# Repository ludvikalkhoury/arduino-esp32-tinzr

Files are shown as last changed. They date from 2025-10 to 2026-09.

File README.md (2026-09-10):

# TinZr ESP32-C3 Arduino Board Manager Package

This repository contains the **TinZr**, an ESP32-C3-based custom board definition for the Arduino IDE.  
It provides a clean, Boards-Manager-installable package so anyone can use your board with one simple URL.

## Publication
The manuscript describing this work is available at: https://www.sciencedirect.com/science/article/pii/S246806722600101X.
It is also included in this repository (`TinZr_Manuscript.pdf`). 

Additionally, all production materials, including printed circuit board (PCB) design files, 3D-printable enclosure models, and component lists, are available at: https://zenodo.org/records/21892119

If you use this work, please cite:
> **Alkhoury, L.**, Moore, T., Swissler, P., Hill, N. J., Shah, S. A., & Kam, M. (2026). TinZr: A compact wireless ESP32-C3 platform for multi-modal physiological sensor integration and data acquisition. HardwareX, e00833.

---
## Pinout
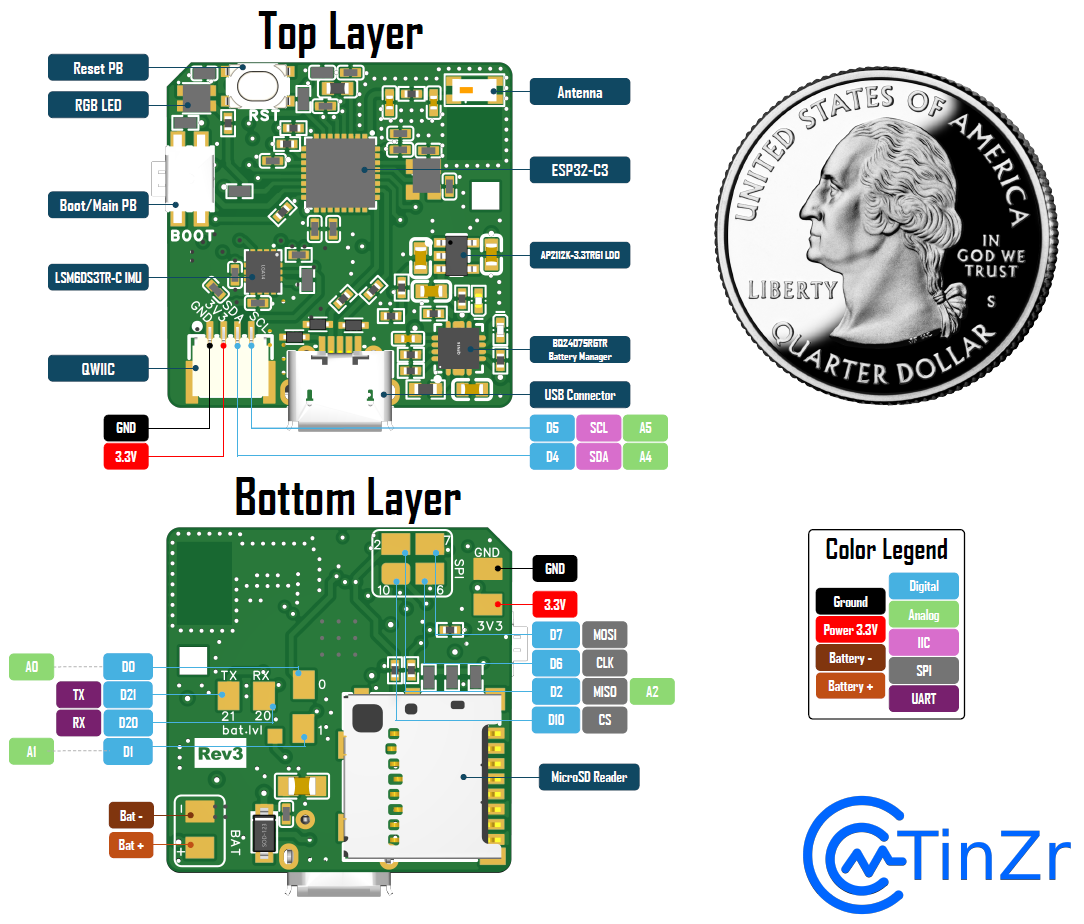
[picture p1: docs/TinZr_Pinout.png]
TinZr ESP32-C3 Pinout


## 🚀 Quick Install

### 1️⃣ Install Espressif ESP32
Open the Arduino IDE and go to:
- Go to **Tools → Board → Boards Manager**
- Find ``esp32 by Espressif Systems``
- Install *only* version `3.3.4`

**⚠️ IMPORTANT: This project is tested and supported exclusively with ESP32 core version `3.3.4`.**  
**Do NOT use any other version — builds may fail or behave incorrectly.**

### 2️⃣ Add the Boards Manager URL
Open the Arduino IDE and go to:

**File → Preferences → Additional Boards Manager URLs**, then paste:

```
https://ludvikalkhoury.github.io/TinZr/package_tinzr_index.json
```

Click **OK**.

### 3️⃣ Install the board package
In Arduino IDE:
- Go to **Tools → Board → Boards Manager**
- Search for **TinZr**
- Click **Install**

### 4️⃣ Select your board
Go to:

**Tools → Board → TinZr Boards → TinZr ESP32-C3 Rev5**

### 5️⃣ Install `TinZrConnect` as a Zipped Arduino Library
#### A) Create the ZIP (IMPORTANT: zip the *library folder*, not the whole TinZr repo)
- Navigate to the `libraries` directory. There you will find the `TinZrConnect` folder (the one that contains `library.properties`).
- Create a zipped version of the `TinZrConnect` folder, and name it `TinZrConnect.zip`.

#### B) Install the ZIP in Arduino IDE
1. In Arduino IDE, go to:
   - **Sketch → Include Library → Add .ZIP Library…**
2. Select `TinZrConnect.zip`
3. Wait for the confirmation message (bottom status bar).

#### C) Verify Installation
1. Go to:
   - **File → Examples**
2. Scroll to find:
   - **TinZrConnect**
3. Open an example sketch and compile.

If you see the examples and the sketch compiles, the library is installed correctly ✅

## 💡 Example Sketch (NeoPixel Test)

```cpp
#include <Arduino.h>
#include "TinZrCore.h" // this library declares TinZrCore TinZr
#include "TinZrLED.h"  // this library declares TinZrStatusLED TinZrLED

void setup() {
    TinZr.begin(25); //LED brightness is 25
}

void loop() {
    TinZrLED.setColor(255,0,0); delay(500);
    TinZrLED.setColor(0,255,0); delay(500);
    TinZrLED.setColor(0,0,255); delay(500);
}
```

#

Copyright © 2026 Ludvik Alkhoury

This software is licensed under the GNU General Public License v3.0.
Commercial licensing options are available upon request.

OSHW Facts

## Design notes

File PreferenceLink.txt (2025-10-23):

File → Preferences → Additional Boards Manager URLs:

https://ludvikalkhoury.github.io/arduino-esp32-tinzr/package_tinzr_index.json

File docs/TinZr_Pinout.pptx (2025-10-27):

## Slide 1

Top Layer

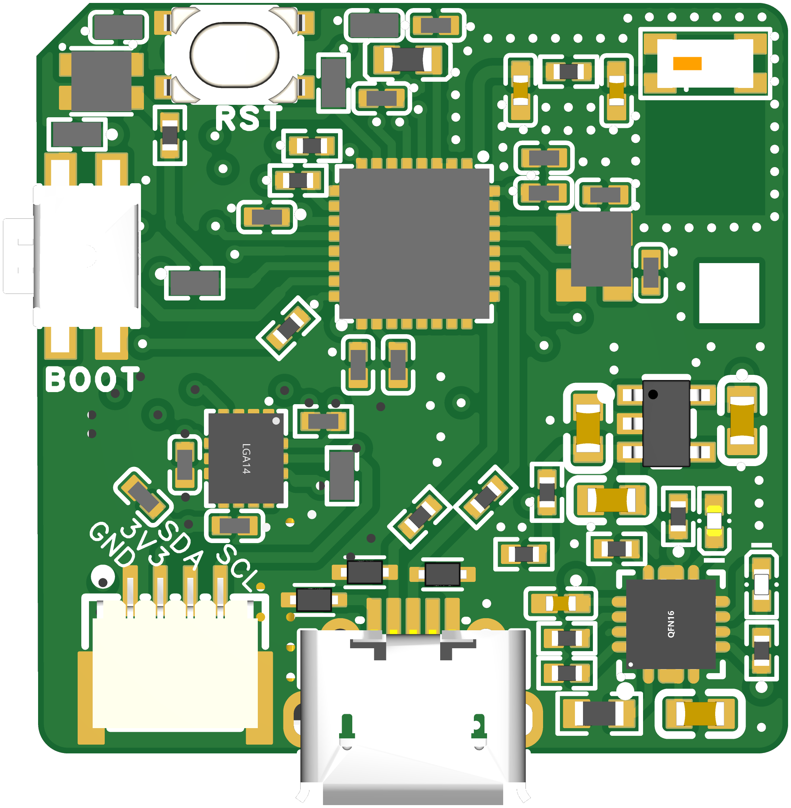
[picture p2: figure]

Reset PB

RGB LED

Antenna

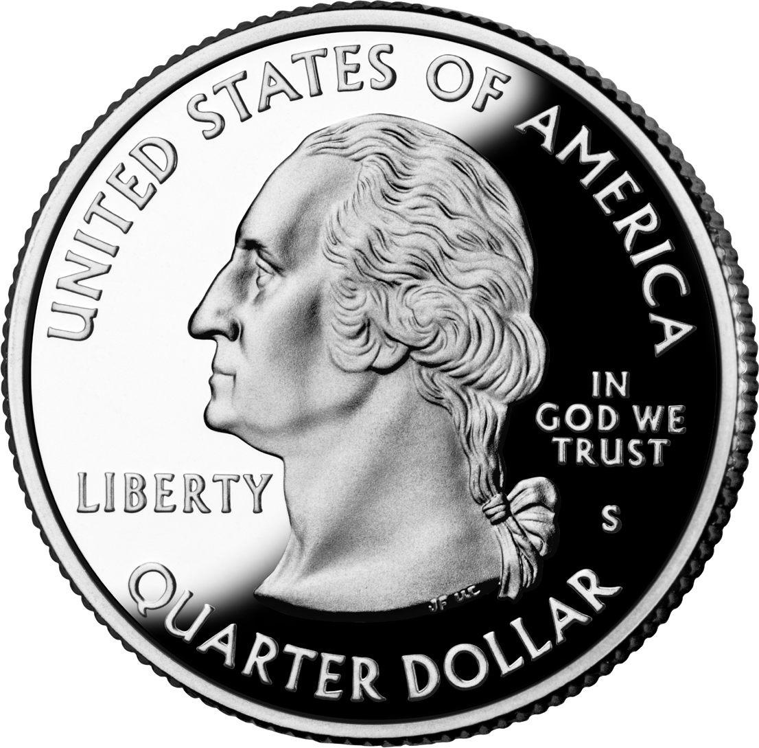
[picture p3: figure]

ESP32-C3

Boot/Main PB

LSM6DS3TR-C IMU

AP2112K-3.3TRG1 LDO

QWIIC

D5

D4

USB Connector

Bottom Layer

BQ24075RGTR
Battery Manager

GND

SCL

A5

3.3V

SDA

A4

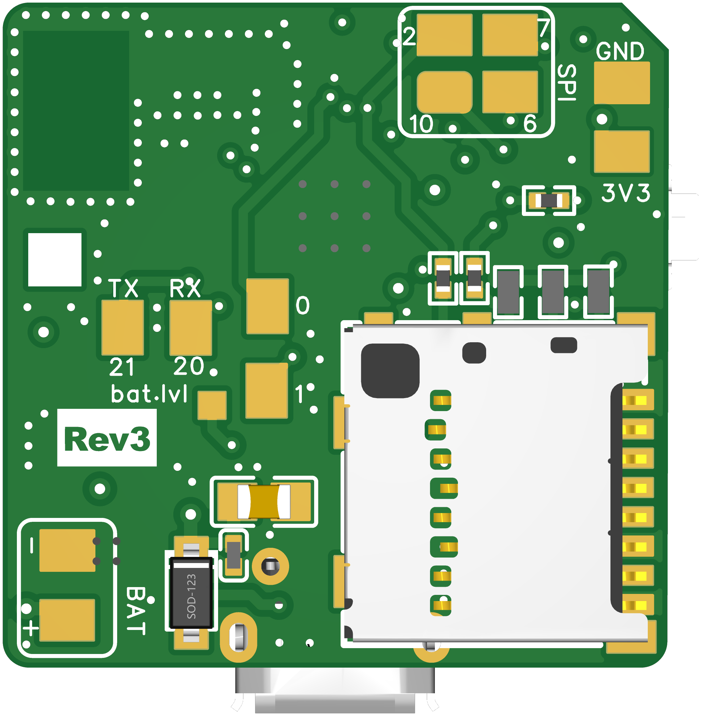
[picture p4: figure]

3.3V

GND

Color Legend

Power 3.3V

Battery -

Ground

IIC

SPI

Digital

Analog

Battery +

UART

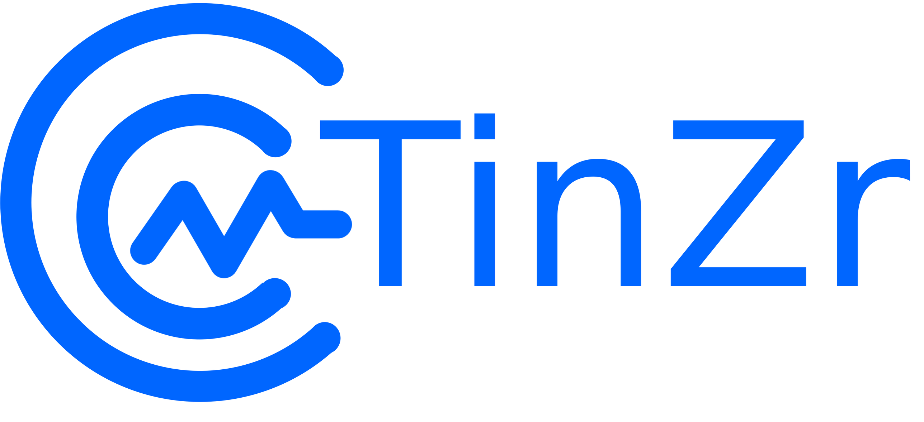
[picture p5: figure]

A0

TX

D21

D0

D2

D6

D7

MISO

MOSI

CLK

A2

A1

RX

D1

D20

D10

MicroSD Reader

CS

Bat -

Bat +

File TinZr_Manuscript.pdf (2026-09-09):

Contents lists available at ScienceDirect (https://www.elsevier.com/locate/ohx)

# HardwareX

journal homepage: www.elsevier.com/locate/ohx

### Hardware article

## TinZr: A compact wireless ESP32-C3 platform for multi-modal physiological sensor integration and data acquisition

## Ludvik Alkhoury a,∗ , Tony Moore b , Petras Swissler c

## , N. Jeremy Hill d,e

,

## Sudhin A. Shah a

## , Moshe Kam f,∗

a Department of Radiology, Weill Cornell Medicine, NY, 10065, USA
b Mortronics Limited, Folkstown, Balbriggan, Dublin, Ireland
c Mechanical Engineering Department, New Jersey Institute of Technology, Newark, NJ 07102, USA
d National Center for Adaptive Neurotechnologies, Stratton VA Medical Center, Albany, NY 12208, USA
e Electrical and Computer Engineering Department, State University of New York at Albany, NY 12222, USA f Electrical and Computer Engineering Department, New Jersey Institute of Technology, Newark, NJ 07102, USA

A R T I C L E I N F O

Keywords:
ESP32-C3 microcontroller
Wearable devices
Multimodal physiological signal acquisition Multi-device coordination
Wireless communication
MicroSD data logging

A B S T R A C T

Microcontrollers have become central to wearable technologies. As these systems continue to evolve, both form factor and functional integration have become critical design considerations. In this study, we present TinZr, a compact, wireless, and open-source ESP32-C3-based microcontroller that serves as a central hub for interfacing with external sensing modules, data logging, and wireless transmission. The TinZr integrates an inertial measurement unit (IMU), an onboard battery management circuit, Wi-Fi and Bluetooth Low Energy, a microSD card reader, and multiple GPIOs supporting digital, analog, I

2C, SPI, and UART interfaces. The complete system measures only 25 mm × 25 mm, making it well-suited for wearable applications. All production files, including printed circuit board (PCB) design, firmware, and a 3D model of a wearable enclosure, are publicly available. Three primary use cases for TinZr are demonstrated:
(a) multi-device communication and coordination, (b) wireless IMU data acquisition, and (c) simultaneous multi-modal physiological signal acquisition using external electrocardiography (ECG) and photoplethysmography (PPG) sensing modules. The TinZr supports both real-time data streaming via Wi-Fi/BLE and local logging to a microSD card. Local logging makes the TinZr suitable for extended research experiments and field studies where continuous wireless connectivity may not be available. An accompanying Arduino library, TinZrConnect, is provided to facilitate programming and integration with existing systems. Overall, the combination of compact design, wireless flexibility, and open-source accessibility makes TinZr a versatile solution for various sensing applications.

∗ Corresponding authors.

E-mail addresses: Lua4006@med.cornell.edu (L. Alkhoury), Kam@njit.edu (M. Kam).

https://doi.org/10.1016/j.ohx.2026.e00833
Received 3 February 2026; Received in revised form 14 August 2026; Accepted 20 August 2026

## HardwareX 28 (2026) e00833 (https://doi.org/10.1016/j.ohx.2026.e00833)

## Available online 28 August 2026

2468-0672/© 2026 The Authors. Published by Elsevier Ltd. This is an open access article under the CC BY-NC-ND license (http://creativecommons.org/licenses/by-nc-nd/4.0/).

L. Alkhoury et al.

Specifications table

Hardware name | TinZr
Subject area | • Electrical and biomedical engineering
| • Neuroscience
| • Swarm robotics
| • Educational tools and open source alternatives to existing
| infrastructure
Hardware type | • Measuring physical properties and in-lab sensors
| • Field measurements and sensors
| • Electrical and biomedical engineering
| • Multi-functional microcontroller platform
| • Compact and wearable embedded controller
| • Wireless data acquisition and communication system (Wi-Fi/BLE)
| • Real-time signal processing
| • Multi-modal physiological signal acquisition and sensor interfacing
| (ECG, PPG, IMU) • Digital communication protocols support (I²C, SPI, UART, GPIO)

Closest commercial
analog
- Seeed XIAO ESP32-C3
- ESP32-C3 Mini
- DFRobot Beetle ESP32-C6
- Adafruit GEMMA v2
- Teensy 4.1
Open source license | CERN Open Hardware Licence (OHL) v2.0 Permissive (hardware), GNU General Public License (GPL) v3.0 (software)
Cost of hardware | $65/unit (including shipping and customs duties)
Source file repository | https://doi.org/10.5281/zenodo.21892119
OSHWA certification UID | US002796

### 1. Hardware in context

Wearable sensing platforms are gaining popularity for their ability to deliver non-invasive, continuous health insights to athletes, patients, and everyday users — while evolving to incorporate sophisticated on-device sensors and analytics. The global wearable sensors market was valued in 2024 at USD 1.4 billion and is projected to grow to USD 6.3 billion by 2033, at a compound annual growth rate (CAGR) of 18.3% over 2025–2033 [1,2]. This surge is largely driven by growing demand for telehealth, long-term monitoring, real-time health tracking, and military applications.
Physiological signal monitoring has become increasingly widespread, with wearable systems now employed by athletes, patients, soldiers, and everyday users to enable continuous health and performance tracking [3–6]. Consequently, many everyday wearables (e.g., watches) now go beyond basic functionality by including onboard sensing hardware, such as accelerometers for activity and motion tracking [7]; photoplethysmography (PPG) sensors for heart rate [8] and oxygen saturation calculation [9]; electrocardiography (ECG) sensors for cardiac rhythm monitoring [10]; temperature sensors for body or skin thermal profiling [11]; and even biochemical sensors for measuring variables like glucose [12], for richer health and activity monitoring [4,13]. Wearable systems for physiological monitoring increasingly depend on microcontroller units (MCU) and platforms that provide tight integration, compact form factors, and support for multi-modal sensing. The continued miniaturization and increasing computational capability of modern MCUs have made it possible to embed real-time sensing, processing, and wireless communication within small, battery-powered systems. Additionally, such MCUs offer sufficient local processing power, robust data logging, and versatile interfaces for auxiliary modules such as inertial, optical, and electrophysiological sensors.
Several open hardware and research platforms have emerged to address these challenges. For instance, CogWatch [14] is an open-source multi-sensor wrist platform that integrates heart rate, respiration, skin conductance, and temperature sensing, to study physiological and behavioral responses in daily activities. CogWatch uses the Adafruit QT Py ESP32-S2 MCU [15] for data acquisition and measures around 29 mm × 38 mm (just the PCB without any sensor enclosures). H-Watch [16] extends these capabilities into a wristwatch-like platform that incorporates multiple radios and energy harvesting, maintaining ultra-low power consumption for long-term wearable deployment. The main purpose of H-Watch is early COVID-19 detection. BioGAP-Ultra [17] is a modular edge-AI platform that supports synchronized acquisition of EEG, EMG, ECG, and PPG signals with on-device processing and flexible form factors. The BioGAP-Ultra firmware runs on the nRF5340 SoC using the Zephyr RTOS, and the accompanying Android software suite enables background data reception, real-time visualization, some parameter configuration, and data storage. Finally, the Multi-Sensor Wearable Health Device (MWHD) framework [18] uses the CC2640R2F Cortex®-M3 [19] MCU for real-time heart rate and

peripheral oxygen saturation (SpO2

) monitoring from PPG signals, temperature, and motion, coupled with wireless data transmission

Table 1
Features and price comparison between some commercially available controllers and TinZr in terms of dimensions, GPIOs, interfaces, and price.

Seeed XIAO
ESP32-C3 [20]

DORHEA
ESP32-C3 Mini
[21]

DFRobot Beetle
ESP32-C6 [22]

Adafruit GEMMA
v2 [23]

PJRC Teensy 4.1
[24]

TinZr

Dimensions
(mm)
21 x 17.8 | 22 x 18 | 25 x 20 | 28 (diameter) | 61 x 18 | 25 x 25
Nbr. GPIOs | 11 | 11 | 13 | 3 | 55 | 10
Nbr. Analog Pins | 4 | 4 | 7 | 1 | 18 | 5
Nbr. Digital Pins | 11 | 11 | 13 | 3 | 55 | 10

I

2C | Yes | Yes | Yes | Yes | Yes | Yes
SPI | Yes | Yes | Yes | Yes | Yes | Yes
UART | Yes | Yes | Yes | No | Yes | Yes
On-board MicroSD Card Reader | No | No | No | No | Yes | Yes

On-board Battery

Management

Yes | No | Yes | No | No | Yes

On-board QWIIC

Connector

No | No | No | No | No | Yes
On-board IMU | No | No | No | No | No | Yes
On-board Controllable RGB LED | No | No | No | No | Yes | Yes

On-board Push
Button

Yes
(Reset & Boot)

Yes
(Reset & Boot)

Yes
(Reset & Boot)

Yes
(Reset)
| | | | Yes | Yes (Reset & Boot/Control)

Unit Price (in
USD)
(January, 2026)
∼ $5 − 10 | ∼ $8 − 12 | ∼ $7 − 10 | ∼ $9.95 | ∼ $30 − 50 | ∼ $65

and mobile application feedback. Together, these platforms illustrate the state-of-the-art in wearable microcontroller integration, where the convergence of low-power embedded processing, miniaturization, and open hardware design has enabled compact, reconfigurable, and affordable solutions for physiological signal monitoring.
Some of the above-mentioned platforms demand significant expertise to program or extend at the driver and firmware level. However, there are compact and flexible MCUs that can be easily programmed via the Arduino ecosystem — making them highly accessible for rapid prototyping, research deployments, and wearable device development. For example, we list several widely used controllers such as Seeed XIAO ESP32-C3 [20], DORHEA ESP32-C3 Mini [21], DFRobot Beetle ESP32-C6 [22], Adafruit GEMMA v2 [23], and PJRC Teensy 4.1 [24]. In general, most of these controllers are compact and thus suitable for wearable applications. The Seeed XIAO ESP32-C3 is very compact and offers Wi-Fi/BLE connectivity with onboard battery management, though it lacks a microSD card reader and a dedicated on-board QWIIC connector for plug-and-play I

2C peripheral expansion. The DORHEA ESP32-C3 Mini does not include battery management, an on-board QWIIC connector, or an SD card interface. The DFRobot Beetle ESP32-C6 similarly lacks an SD card reader and an on-board QWIIC connector. The Adafruit GEMMA v2 is extremely small and lightweight but does not include a charging unit, SD card reader, or an on-board QWIIC connector. The PJRC Teensy 4.1 includes an SD card reader, making it well-suited for data logging, but it lacks Wi-Fi/BLE and is physically bulkier than the other options.
In this study, we introduce the TinZr, which builds on existing designs by providing a fully wireless controller in a compact 25 mm × 25 mm form factor, combining sensing, data logging, and communication in an open-source package. It uses the ESP32-C3 MCU and integrates an inertial measurement unit (IMU) comprising a 3-axis accelerometer and 3-axis gyroscope, battery management circuitry, Wi-Fi and BLE 5.0 connectivity, a microSD card reader, and GPIOs supporting digital, analog, I

2C (it provides
an on-board QWIIC connector), SPI, and UART. While TinZr can directly acquire analog signals through its onboard ADC, many physiological sensing applications require dedicated sensor modules or analog front-end circuitry to provide signal conditioning, amplification, filtering, and digitization. In such configurations, TinZr serves as the central acquisition, coordination, data logging, and communication hub for the connected sensing devices. A detailed specification comparison between the commercially available controllers and the TinZr is available in Table 1. Importantly, the TinZr can be programmed via the Arduino ecosystem, lowering the barrier to use. This functional density enables multimodal physiological signal acquisition, on-device processing, and flexible data handling (wireless streaming or local logging). All production files for the TinZr, including PCB designs and 3D enclosure models for wearables applications, are publicly available at https://doi.org/10.5281/zenodo.21892119. The onboard microSD reader supports long-duration, high-resolution logging, essential for field or extended experiments where continuous wireless transmission may

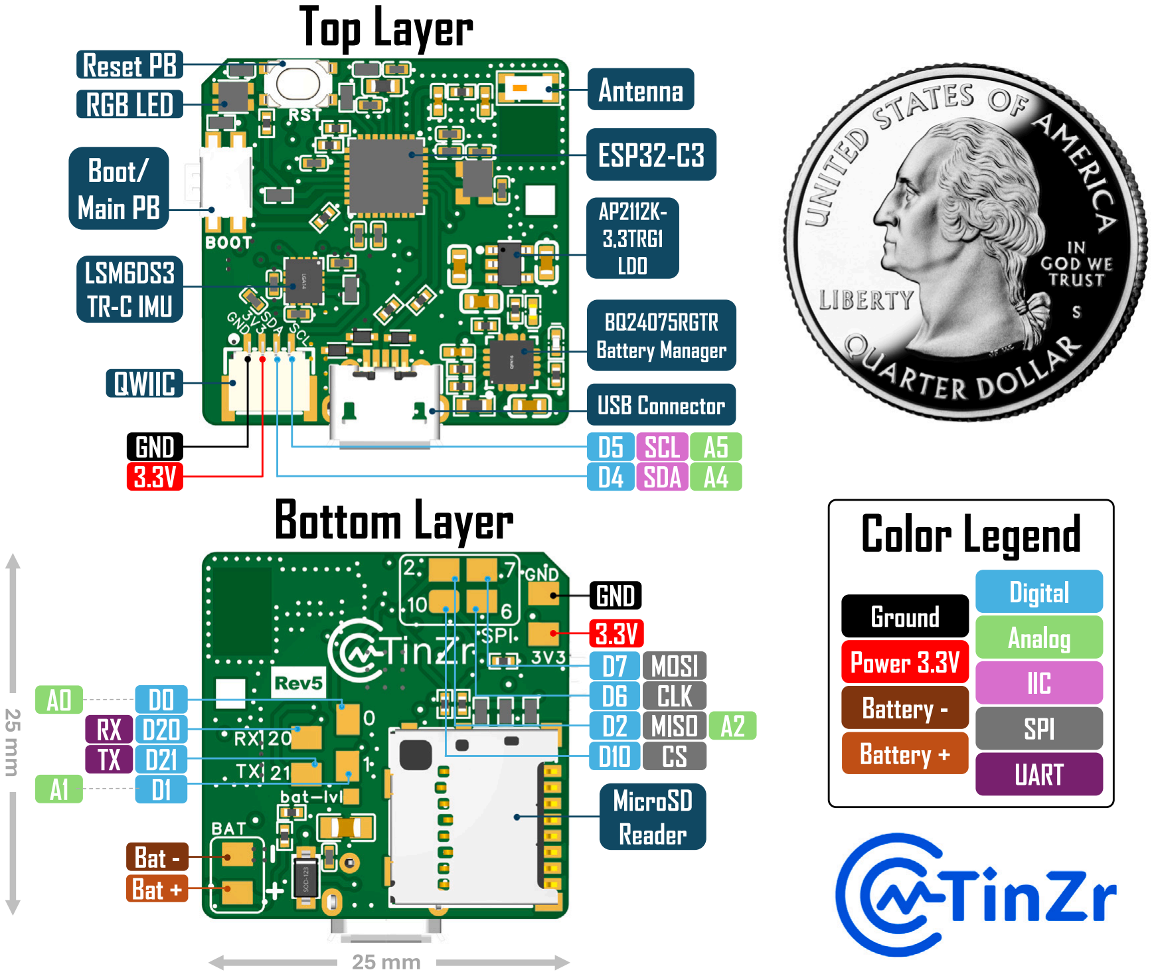
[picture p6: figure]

Fig. 1. TinZr pinout diagram showing the available GPIOs, communication interfaces, power rails, and key functional connectors.

not be feasible. Wireless connectivity via Wi-Fi and BLE remains available when real-time streaming is needed. We provide an accompanying Arduino library, TinZrConnect, to facilitate programming and integration of TinZr with existing systems.
Overall, TinZr offers a low-cost and compact alternative that surpasses lighter platforms by combining local storage, wireless flexibility, and standardized sensor interfacing in a single module.

### 2. Hardware description

Our repository, available at https://doi.org/10.5281/zenodo.21892119, provides the following materials:
- raw and editable schematics and PCB layout files used in the design of the TinZr ESP32-C3 Rev5; PCB layouts are provided in

.eprj format for EasyEDA Pro [25], as well as in .kicad_pcb/.kicad_sch format for KiCad [26];
- a 3D model of the wearable enclosure, designed to house the TinZr device and battery, provided in .step format and

compatible with FreeCAD [27] and other CAD software;
- exported manufacturing files, including Gerber files, pick-and-place data, and bills of materials (BOM) for the PCBs, as well

as .stl files for 3D printing the wearable enclosure.

Fig. 1 illustrates the TinZr pinout along with the top and bottom layers of the PCBA. Fig. 2 shows the 3D model of the wearable TinZr enclosure, illustrating the exploded and assembled views used to house the PCBA and battery. The major functional blocks and embedded components of the system are described in the following subsections.

### 2.1. ESP32-C3 development board

The central component of the TinZr is an ESP32-C3-based microcontroller module, labeled ‘‘ESP32-C3’’ in Fig. 1. The ESP32-C3 module integrates a single-core RISC-V processor with native 2.4 GHz Wi-Fi and Bluetooth Low Energy (BLE) connectivity,

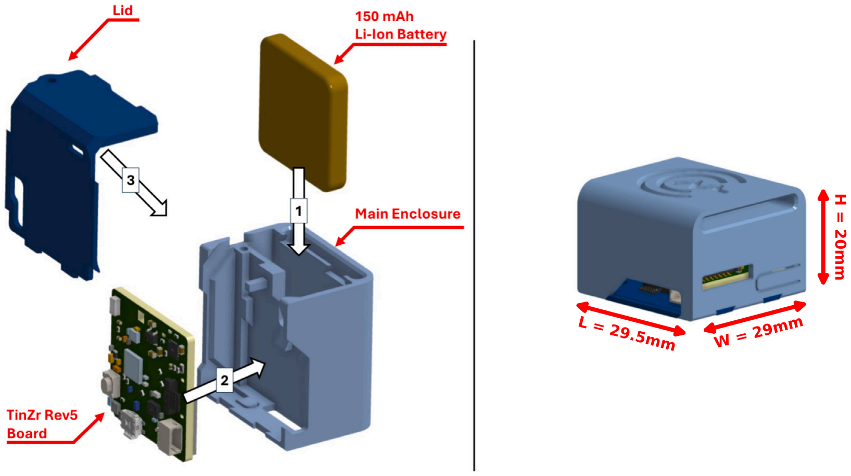
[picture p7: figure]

Fig. 2. 3D model of the TinZr wearable enclosure illustrating the mechanical design used to enclose the PCBA and battery for wearable applications. The exploded view (left panel) shows the individual enclosure components, including the main enclosure, top lid, battery lid, TinZr Rev 5 PCBA, and 150 mAh Li-ion battery, while the assembled view (right panel) shows the fully assembled enclosure (length = 29.5 mm, width = 29 mm, and height = 20 mm). Dashed orange arrows in the exploded view indicate the assembly directions and relative placement of each component during enclosure assembly.

providing a compact and power-efficient solution well suited for wearable and portable applications. The processor operates at clock frequencies of up to 160 MHz, offering sufficient computational performance for real-time control, coordination, and wireless communication tasks.
The ESP32-C3 module provides a sufficient number of general-purpose input/output (GPIO) pins to support the required digital and analog interfaces, including I

2C, SPI, and UART communication buses, while maintaining low power consumption during both active operation and deep sleep modes. Although the ESP32-C3 module offers fewer GPIOs than larger development boards such as the Teensy 4.1, the pin allocation in TinZr was carefully designed to prioritize the interfaces and peripherals most relevant to physiological signals coordination, wearable sensing, and wireless data transfer. As a result, all core system functionalities are supported without reliance on external multiplexing or expansion hardware.
The ESP32-C3 module is positioned centrally on the TinZr PCBA, with its USB interface accessible at the board edge to facilitate firmware development, debugging, and power delivery (Fig. 1).
Overall, the ESP32-C3 module provides a compact, wireless, and power-efficient computational core that enables TinZr’s functionality while supporting scalable, open-hardware development.

### 2.2. Inertial measurement unit (IMU)

Motion sensing in the TinZr platform is provided by an STMicroelectronics LSM6DS3TR-C inertial measurement unit (IMU), labeled ‘‘LSM6DS3TR-C IMU’’ in Fig. 1. The LSM6DS3TR-C unit integrates a 3-axis accelerometer and a 3-axis gyroscope in a compact, low-power package, enabling continuous monitoring of linear acceleration and angular velocity.
The accelerometer supports selectable full-scale ranges up to ±16 g, while the gyroscope supports angular rate measurements up to ±2000 dps, allowing the device to capture both fine-grained motion and high-dynamic activities. The IMU supports output data rates up to several kilohertz and communicates with the ESP32-C3 module via the I

2C bus, providing reliable and low-latency motion data acquisition.
The LSM6DS3TR-C unit was selected for its low power consumption, small footprint, and proven reliability in wearable and embedded applications. In the context of TinZr, IMU data can be used to support motion-aware sensing, artifact detection, and coordination tasks, particularly in mobile and wearable experimental settings.

### 2.3. Battery management and power regulation

Power management in the TinZr platform is handled by a Texas Instruments BQ24075RGTR battery management integrated circuit, labeled ‘‘BQ24075RGTR Battery Manager’’ in Fig. 1. The BQ24075RGTR is a single-cell lithium-ion/lithium-polymer (Li-ion/Li-Po) charger integrated circuit (IC) with power-path management, enabling simultaneous battery charging and system operation.

The device supports USB-compatible input sources and provides regulated power to the system while safely managing battery charging, including preconditioning, constant-current, and constant-voltage charging phases. Integrated safety features, such as thermal regulation, overvoltage protection, and charge termination, ensure reliable and safe operation in wearable and portable applications.
Power-path management allows TinZr to operate directly from an external power source when available, while automatically switching to battery power when disconnected, without interrupting system operation. This capability is particularly important for long-duration experiments and mobile use cases, where uninterrupted operation and safe battery handling are critical. The BQ24075RGTR was selected for its compact footprint, low external component count, and proven reliability in battery-powered embedded systems.
The charging behavior of the BQ24075RGTR unit in TinZr is configured using three external resistors connected to the ‘‘ISET’’, ‘‘ILIM’’, and ‘‘TMR’’ pins. The fast-charge current is set by a resistor on the ‘‘ISET’’ pin. With an 8.2 kΩ resistor, the resulting charge current is approximately 100 mA, which is well matched to the 150 mAh single-cell lithium-polymer (Li-Po) battery [28] used with the TinZr and corresponds to a charge rate of approximately 0.67C.
The maximum input current drawn from the external power source is limited via the ‘‘ILIM’’ pin to ensure compatibility with USB power supplies while supporting simultaneous system operation and battery charging. With a 3 kΩ resistor connected to ‘‘ILIM’’, the input current is limited to approximately 520 mA, providing sufficient headroom for system operation while remaining within typical USB power constraints.
In addition, a resistor connected to the ‘‘TMR’’ pin sets the safety timeout for the charging process. With a 46.4 kΩ resistor, the precharge safety timer is approximately 37 min, and the fast-charge safety timeout is approximately 6.2 h, providing protection against abnormal charging conditions. These resistor values were selected specifically for the 150 mAh battery [28] used with the TinZr, and can be adjusted (by desoldering the onboard resistors and replacing them with desired ones) to accommodate larger-capacity batteries by increasing the allowable charge and input currents, while maintaining manufacturer-recommended charge rates and thermal limits.
The battery is soldered directly to the rear side of the PCB at the pads labeled (+) and (-), ensuring correct polarity and compact mechanical assembly.

### 2.4. On-board controllable RGB LED

TinZr includes an addressable RGB status LED (‘‘NeoPixel’’-class), labeled ‘‘RGB LED’’ in Fig. 1. This type of LED integrates red, green, and blue emitters together with a small control driver in a single package, allowing the LED color and brightness to be digitally controlled from a single microcontroller GPIO pin.
The RGB LED can be programmed to provide a visual indication of device state during development and deployment (e.g., BLE advertising/connection state, recording status, or error conditions). Since the LED can draw non-negligible current at high brightness, TinZr firmware limits brightness and disables the LED during low-power operation when appropriate. This feature preserves battery life while retaining a simple, user-facing diagnostic interface.
The RGB LED is a fully software-controllable indicator intended for general system feedback and debugging. TinZr also includes dedicated power and charging LEDs (bottom right corner of the top layer in Fig. 1) that operate independently of firmware, providing a visual indication of device power and battery charging status.

### 2.5. MicroSD card interface

Local data storage in the TinZr platform is provided by an on-board microSD card reader, labeled ‘‘microSD Reader’’ in Fig. 1. The microSD interface allows sensor data, timestamps, and system logs to be stored directly on removable flash media, enabling fully standalone operation without reliance on a continuous wireless connection.
The microSD card communicates with the ESP32-C3 module via the SPI bus, providing a simple and widely supported interface for embedded systems. This design choice ensures broad compatibility with standard microSD cards and commonly used embedded file systems, while maintaining predictable timing and resource usage. The SPI-based implementation also simplifies integration alongside other peripherals on the shared communication bus.
The inclusion of local storage is particularly important for long-duration recordings, field deployments, and wearable experiments where wireless bandwidth or connectivity may be limited or unavailable. By offloading data logging to the microSD card, TinZr supports reliable data capture without requiring continuous wireless transmission. We validated data logging using a 32 GB microSDHC card (Silicon Power Elite, FAT32-formatted).

### 2.6. QWIIC connector

The TinZr platform includes an on-board QWIIC-compatible expansion connector, labeled ‘‘QWIIC’’ in Fig. 1, providing a standardized interface for external peripheral integration. The QWIIC connector exposes the I

2C bus along with power and ground, enabling rapid connection of compatible sensors and modules without soldering.
By leveraging the I

2C interface, the QWIIC connector allows additional devices — such as environmental sensors, auxiliary motion sensors, or other low-power peripherals — to be easily integrated into the system. This design supports modular expansion while minimizing wiring complexity and reducing the risk of incorrect connections during prototyping or deployment.

The inclusion of a QWIIC connector enhances the flexibility of the TinZr platform by enabling rapid hardware extensions without modifying the core PCB design. This feature is particularly useful for experimental and research-oriented applications, where sensor configurations may evolve over time or vary between deployments.

### 2.7. Reset and user push buttons

TinZr includes two on-board push buttons: a dedicated reset button, labeled ‘‘Reset PB’’, and a multifunction push button, labeled ‘‘Boot/Main PB’’ in Fig. 1. The reset button provides a hardware reset of the ESP32-C3 module, allowing the system to be restarted without cycling power during development or troubleshooting.
The main button serves a dual purpose. When used in conjunction with the reset button, it can be used to place the ESP32-C3 module into bootloader mode for firmware flashing (see ‘Program’ in Section 6.1). During normal operation, the main button can be repurposed by the firmware as a general user input, enabling application-specific functionality such as mode selection, event marking, or user interaction.
The main button is implemented as right-angle (90◦
) tactile switch. This orientation allows the button to be actuated from the side of the enclosure rather than the top surface of the PCB, simplifying mechanical integration and improving usability in compact enclosures. The right-angle design is particularly advantageous for wearable applications, where low profile, accessibility, and protection against accidental presses are important considerations.

### 2.8. Micro-USB connector

The TinZr platform includes a micro-USB connector, labeled ‘‘USB Connector’’ in Fig. 1. It provides both power input and a wired communication interface to the ESP32-C3 module. This connector is used for battery charging via the on-board power management circuitry as well as for firmware flashing, debugging, and development during device configuration.
When connected to an external power source, the micro-USB interface supplies power to the system and enables charging of the on-board Li-Po battery through the BQ24075 battery management IC. During development, the same interface allows firmware to be uploaded to the ESP32-C3 module and supports serial communication for debugging and status monitoring.
The micro-USB connector was selected for its compact form factor, mechanical robustness, and wide availability of cables, making it well suited for both early-stage development and enclosed wearable applications. Its placement at the edge of the PCB facilitates straightforward access when the device is integrated into a protective enclosure.
Given TinZr’s flexibility, reprogrammability, and support for a wide range of external sensors and communication interfaces, it can be adapted to many research applications both within and beyond wearable physiological monitoring. We envision its principal use cases as follows, although this list is by no means exhaustive:
- Wearable and portable sensing: TinZr can serve as a compact, battery-powered platform for acquiring motion, physiological,

environmental, or other sensor data in laboratory, ambulatory, and field-based experiments.
- Custom multi-sensor data acquisition: External sensing modules can be integrated through I
2C, SPI, UART, analog, or
digital interfaces, allowing researchers to develop application-specific and multi-modal sensing systems without redesigning the central controller.
- Standalone and wireless data collection: Sensor data can be wirelessly streamed in real time over BLE or Wi-Fi, or stored

locally on the onboard microSD card, enabling both interactive laboratory experiments and longer-duration recordings where continuous wireless connectivity may not be available.
- Multi-device communication and coordination: Multiple TinZr units can communicate with a central host and be controlled

individually or collectively, enabling coordinated multi-device sensing, simultaneous measurements across multiple devices, and swarm-style experimental applications.

Design filename | File type | License | Location of the file
TinZr Rev 5 PCB | raw schematics, *.svg & *.kicad_sch; PCB sketches, *.kicad_pcb; EasyEDA Pro source, *.eprj; manufacturing files, *.grb & *.csv
CERN OHL-P 2.0 | https://doi.org/10.5281/zenodo.21892119

Enclosure 3D
designs

source, *.step;
manufacturing, *.stl
| CERN OHL-P 2.0 | https://doi.org/10.5281/zenodo.21892119

BOM of all
components
*.csv | CERN OHL-P 2.0 | https://doi.org/10.5281/zenodo.21892119
Firmware code | Arduino IDE source,
*.ino; Python-based GUIs, *.py | GNU General Public License, version 3 (GPLv3) | https://github.com/ludvikalkhoury/TinZr.git

### 3. Design files summary

- TinZr Rev5 PCBs: design files of TinZr Rev5 PCB are available. These are the raw and editable EasyEDA Pro files (.eprj

format) as well as KiCAD PCB files (.kicad_pcb format). Also available are manufacturing files that can be used directly to produce the PCBs. These are Gerber (.grb), pick and place (.csv), and bill of materials (BOM) (.csv) files.
- Enclosure 3D designs: raw editable 3D design files (in .step format) are available for the TinZr’s wearable enclosure. Also

are available the corresponding .stl files that can be used directly in slicing software to generate a g-code for a 3D printer.
- BOM of all components: a BOM is available that contains all the components we used to build the TinZr Rev5 PCB.
- Firmware code: an Arduino library, TinZrConnect, is available, with examples that can be directly updated and run on the

TinZr.

### 4. Bill of materials (BOM)

We provide a detailed and comprehensive BOM in the TinZr’s Zenodo repository, listing all electronic components along with their part numbers, manufacturers, and supplier IDs.
The cost of making the TinZr Rev5 is around $65 per unit. This per-unit cost assumes a minimum quantity of 5, reflecting the minimum quantity required by the PCB manufacturing company, and include shipping and current customs duties (January 2026).

### 5. Build instructions

Step-by-step instructions are provided, on how to manufacture the TinZr.

### 5.1. PCB manufacturing

As previously mentioned, all the files needed in the PCB manufacturing process are publicly available. These files are Gerber, Pick-and-Place, and BOM, and they can be found in the Zenodo repository. We have used JLCPCB (https://jlcpcb.com/)

1
to manufacture
the boards since it provides a wide variety of base materials and colors and other PCB specifications. We designed and built the TinZr Rev 5 as a 4-layer PCB, using a standard quality PCB with flame retardant (FR-4) as the base material. We picked a PCB thickness of 1.6 mm with a hot air solder leveling (HASL) (with lead) surface finish. We also chose the copper weight on the top and bottom to be 1 oz/ft²
. We used two ground planes (top and bottom).

### 5.2. Wearable enclosure 3D printing

We provide a 3D model (.stl files) for an enclosure designed to fit the TinZr Rev5’s PCBA as well as a 150 mAh Li-Po battery that power the TinZr.
The wearable enclosure was printed using a local Creality Ender-3 3D printer (Fused Deposition Modeling (FDM)), using PLA filaments. The quality of the print was acceptable for our purposes. In case the user requires a higher resolution, we suggest using a higher quality alternatives such as Multi-Jet Fusion (MJF) printing, which could result in a higher-quality product (but comes at a higher price).

### 5.3. Component soldering

For our design, we used the mounting and soldering services provided by JLCPCB to assemble and solder all components on the TinZr board. The only exception was the main push button, which was not available through JLCPCB at the time of ordering and was therefore soldered manually.

### 5.4. Assembly

The TinZr Rev 5 is fully functional out-of-the-box and does not require any assembly for basic operation. However, when integrating the system into a wearable enclosure, the following steps should be followed to properly assemble the wearable unit.

(1) Solder the battery positive (+) and negative (-) leads to the corresponding battery terminals located on the bottom layer of the TinZr board (Fig. 3, Panel A).
(2) Insert the battery into the designated battery compartment and place the TinZr board onto its designated mounting platform within the enclosure (Fig. 3, Panel B).
(3) Clip the snap-fit lid onto the main enclosure to secure the assembly (Fig. 3, Panel C). The wearable unit is now fully assembled and ready for use.

1 Other PCB manufacturers offer comparable services — for example, DKRed (https://www.digikey.com/en/resources/dkred), OSH Park (https://oshpark.com/), (https://oshpark.com/) and PCB Way (https://www.pcbway.com/), to name a few.

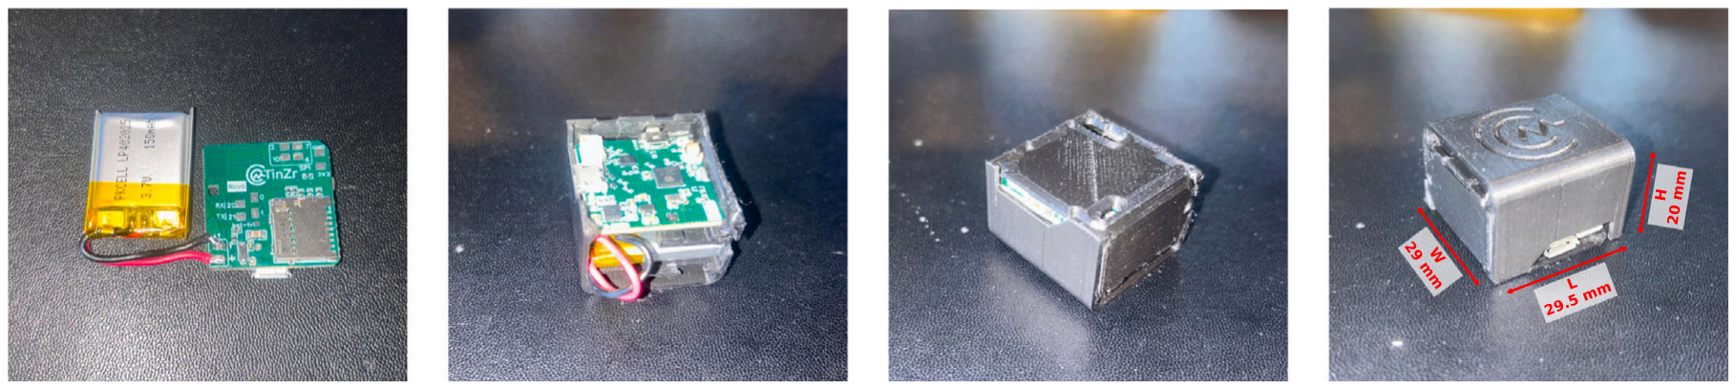
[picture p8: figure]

Fig. 3. Step-by-step illustration on how to assemble the TinZr Rev 5 board with the wearable 3D enclosure (panels A–C), following the steps described in Section 5.4. Panel D shows the fully assembled device (length = 29.5 mm, width = 29 mm, and height = 20 mm).

Panel D of Fig. 3, shows the completed TinZr Rev 5 wearable unit after all assembly steps have been performed.
TinZr provides a battery-level monitoring feature. Battery voltage is measured via the bat-lvl pad, which must be soldered to the Pin 1 pad (see the bottom layer of Fig. 1); this pin is designated in the TinZr firmware as the default battery-sensing input. However, it can be repurposed for other functions when battery-level sensing is not required. This connection is required for the battery level to be reported correctly by the example firmware included in the repository.

### 5.5. Programming

The TinZr Arduino library, TinZrConnect, can be downloaded directly from the TinZr GitHub repository https://github.com/ludvikalkhoury/TinZr.git. (https://github.com/ludvikalkhoury/TinZr.git) In addition to the Arduino library, TinZr provides a custom Arduino Board Manager package with full support for the TinZr Rev 5 hardware, enabling seamless installation and configuration within the Arduino IDE. The TinZrConnect library includes a collection of example sketches designed to test and demonstrate the full functionality of the TinZr Rev 5 board. For instance, the TinZrCore sketch provides a basic demonstration of core hardware features, including the main push button, status LED, and battery level monitoring (assuming the battery-level pad has been soldered to Pin 1 pad as described in Section 5.4). The TinZrComCenter sketch establishes a centralized communication framework in which multiple TinZr devices connect to a single host system acting as a communication hub. In this architecture, each TinZr operates as an independent node that can transmit data and receive control messages over Wi-Fi. The central hub manages all connected devices and can selectively broadcast commands to all TinZr units or address individual devices independently. This design enables coordinated multi-device operation and is well suited for distributed or swarm-style applications, such as coordinated multi-device sensing or collaborative robotics. Another example, TinZrWearableSD, enables communication between one or more TinZr devices and a central PC over Bluetooth Low Energy (BLE), allowing the PC to control recording start and stop events while enabling local logging of inertial measurement unit (IMU) data (accelerometer and gyroscope) as well as red and infrared photoplethysmographic (PPG) data when a MAX30102 sensor [29,30] is connected via QWIIC.
Both TinZrComCenter and TinZrWearableSD are accompanied by graphical user interfaces (GUIs), along with the underlying Python source code, allowing users to operate the system without requiring extensive experience in firmware or software development. In later sections of this paper, we demonstrate the capabilities of the TinZr Rev 5 using TinZrComCenter and TinZrWearable as representative example use cases.

### 6. Operation instructions

### 6.1. User instructions

The TinZr Rev 5 operates similarly to other microcontrollers in the ESP32 family. Here we follow a simple three-step workflow: Power, Program, and Deploy.

(1) Power: The TinZr Rev 5 can be powered either by connecting it to a host computer via USB or by using a connected rechargeable battery for standalone or wearable operation. When powered through USB, a white status LED illuminates, indicating that the board is receiving power. When a battery is connected and charging, a green charging-status LED remains illuminated and turns off once charging is complete. When operating solely on battery power, no LEDs are illuminated. The power and charging status LEDs are located to the left of the USB connector at the same vertical level (see Fig. 1, top layer).
(2) Program: The TinZr Rev 5 can be programmed with any ESP32-compatible firmware, including user-developed sketches or example programs provided with the TinZrConnect library. Programming is performed using the Arduino IDE after selecting the appropriate board and serial port. In some cases, the board must be placed into bootloader mode manually. This is accomplished by pressing and holding the main button, briefly pressing and releasing the reset button while continuing to hold the main button, and then releasing the main button. Once the firmware upload is complete and the program begins execution, the device is ready for use.

(3) Deploy: After programming, the TinZr Rev 5 can be deployed either while connected via USB or as a fully standalone device powered by the onboard battery. In deployed operation, the device can stream sensor data, communicate wirelessly using BLE or Wi-Fi, or operate autonomously depending on the loaded firmware. This flexibility allows the TinZr to function both as a development platform and as an embedded wearable system.

### 6.2. Safety considerations

The TinZr Rev 5 is a low-voltage, battery- and USB-powered microcontroller platform intended for embedded sensing, wearable prototyping, and wireless and local data acquisition. The device does not make direct electrical contact with the wearer, nor does it generate or apply electrical stimulation or excitation signals. As such, when used as intended, the TinZr presents minimal inherent electrical risk.
When deployed in wearable or human-adjacent applications, the TinZr is typically powered solely by its onboard battery and communicates wirelessly via BLE or Wi-Fi. This battery-only, wireless mode of operation significantly reduces the risk of electrical shock associated with mains-powered systems.
If the TinZr is connected to external sensors or peripherals that may contact a human subject, it is the user’s responsibility to ensure that those components meet appropriate electrical safety and isolation standards. The platform does not provide medical-grade electrical isolation and should not be considered a standalone biomedical acquisition device. When used with human-connected sensors, the safety of the overall system depends on the design and validation of the complete measurement chain, including the external analog front-end circuitry, sensors, power supplies, grounding strategy, and any required electrical isolation. Users are responsible for ensuring that the complete system complies with applicable safety standards and institutional requirements for human-subject research. The TinZr Rev 5 has not been tested, certified, or approved for clinical or medical use, and should therefore be used exclusively for research, prototyping, or non-clinical applications unless additional safety certification is obtained. As with most open-source hardware platforms, the TinZr is provided without warranty, and its use is undertaken at the user’s own risk. The authors disclaim all liability to the extent permitted by applicable law.

### 7. Validation and characterization

To validate the operation and characterize the performance of the TinZr Rev 5 platform, we conducted several complementary validation and characterization tests. These tests were designed to evaluate the system across key intended use scenarios, including
(a) multi-device communication and coordination, (b) real-time sensor (IMU) data acquisition, (c) simultaneous multi-modal physiological signal acquisition, (d) power consumption and battery life, and (e) wireless communication performance.

### 7.1. Multi-device communication and coordination

Multi-device communication and coordination were validated using the TinZrComCenter framework. In this configuration, multiple TinZr devices simultaneously connect to a central host system (a personal computer) that functions as a communication hub. The firmware supports bi-directional communication over TCP/IP, enabling both TinZr-to-hub and hub-to-TinZr messaging, as well as broadcast commands addressed to all connected TinZr units. This test case demonstrates the TinZr platform’s ability to support coordinated, multi-node operation, enabling use cases such as distributed sensing, coordinated data acquisition, and swarm-style control architectures. For demonstration purposes, we deployed the Arduino-based firmware located at:

TinZr/libraries/TinZrConnect/examples/TinZrComCenter/TinZrComCenter.ino

First, the user should connect the PC to the same Wi-Fi network to which the TinZrs are intended to connect. In the firmware, the user should provide the Wi-Fi SSID and password, the PC’s IP address, and a hostname for the TinZr onto which the code is flashed. Here, we upload the firmware to two TinZr devices, referred to as TinZrBlack (black-colored enclosure) and TinZrGold (gold-colored enclosure). Next, we launch the companion Python-based graphical user interface (GUI)²
located at:

TinZr/libraries/TinZrConnect/examples/TinZrComCenter/TinZrComCenter.py

After both devices successfully connected to the hub, a broadcast command was issued to set the onboard RGB LEDs to blue by sending the command LED 0 0 255 20, which specifies red, green, and blue color intensities of 0, 0, and 255, respectively, with a low brightness level of 20. As shown in panel A of Fig. 4, the RGB LEDs on both TinZr devices simultaneously turned blue, confirming correct broadcast communication and successful broadcast command execution. Additionally, we can increase the brightness level to 150 and LEDs on both TinZr boards get brighter (panel B of Fig. 4).

2 We also provide an executable file that installs the GUI on the PC without the need to run any Python codes. This file is available in the repository under the TinZrComCenter directory and as part of the repository release.

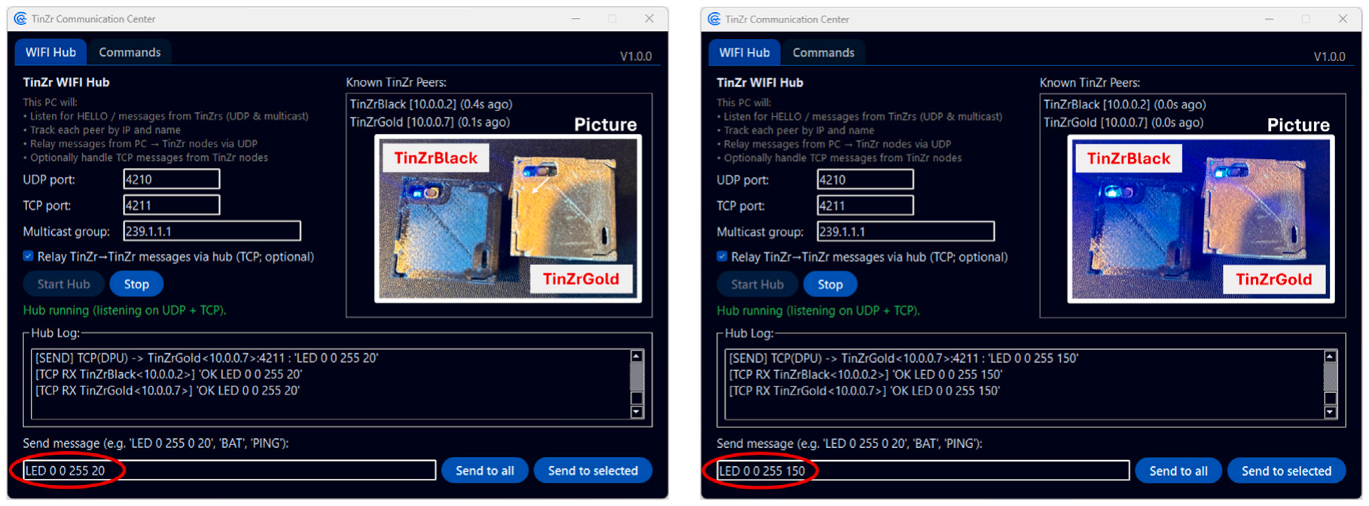
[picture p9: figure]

Fig. 4. Screenshot of the TinZr Communication Center Python-based GUI used for multi-device control over Wi-Fi, alongside a photograph of two TinZr devices (TinZrBlack and TinZrGold). Panel A demonstrates LED control at a low brightness setting (brightness level 20), while panel B shows the same devices driven at a high brightness setting (brightness level 150).

### 7.2. Real-time sensor data acquisition

We also demonstrated end-to-end wirelessly-controlled acquisition of inertial data using the TinZrWearableSD configuration. In this mode, the TinZr device streams inertial measurement unit (IMU) data acquired from the LSM6DS3TR-C sensor, including triaxial accelerometer and gyroscope signals.³ Control of recording operations, including start and stop commands, is handled through an accompanying Python-based graphical user interface (GUI) that communicates with the TinZr devices over BLE, while all sensor data are logged locally to the onboard microSD card. For demonstration purposes, we deployed the wearable firmware located at:

TinZr/libraries/TinZrConnect/examples/TinZrWearableSD/TinZrWearableSD.ino

The user should specify a hostname for the TinZr before flashing the firmware. For the microSD validation presented in this work, the firmware was configured with a sampling interval of 4 ms, corresponding to a target sampling rate of 250 Hz. Data were written to a 32 GB FAT32-formatted microSDHC card as comma-separated values (CSV) files in the /TinZrLogs directory. Each CSV file included a metadata header containing the device name, subject identifier, PC start timestamp, sampling interval, target sampling rate, sensor detection status, and column units. The recorded variables included elapsed time, red and infrared PPG measurements from the MAX30102 (when available), and three-axis accelerometer and gyroscope measurements from the onboard IMU. Specifically, the logged columns were t_ms, red_nA, ir_nA, ax_g, ay_g, az_g, gx_dps, gy_dps, and gz_dps. The firmware also recorded whether the PPG sensor was detected; if unavailable, the red and infrared PPG values were logged as zero. After the firmware is flashed onto the board, we launch the companion Python-based GUI⁴
located at:

TinZr/libraries/TinZrConnect/examples/TinZrWearableSD/TinZrWearableSD.py

For illustration purposes, we collected IMU data under three conditions and report representative snapshots of the streamed sensor data in Fig. 5.
In the first condition, data were collected while the participant sat still while holding the TinZr in the right hand (panel A of Fig. 5). Next, the data were then collected during repetitive hand up-and-down motion at a frequency of 50 bpm (beats per minute) (panel B of Fig. 5). Finally, the motion was repeated at a frequency of 100 bpm (panel C of Fig. 5). The hand-motion frequency was controlled using a metronome.
In the absence of motion, the IMU signals show minimal activity. When motion is introduced, the IMU signals capture the corresponding periodic movement (panel B of Fig. 5). This effect becomes more frequent, with a higher rate of oscillations, as the motion frequency increases from 50 bpm to 100 bpm (panel C of Fig. 5).

3 This firmware also supports the addition of a photoplethysmographic (PPG) sensor, MAX30102 [29,30], when the optical module is present. The MAX30102 interfaces with the TinZr board via an I

2C connection using the onboard QWIIC connector. When no MAX30102 sensor is connected, the corresponding PPG channels are reported as zero-valued signals. An example of red and infrared PPG signals collected from the MAX30102 sensor is available in Section 7.3
4 Similar to the previous example, we also provide an executable file that installs the GUI on the PC without the need to run any Python codes. This file is available in the repository under the TinZrWearableSD directory, and as part of the repository release.

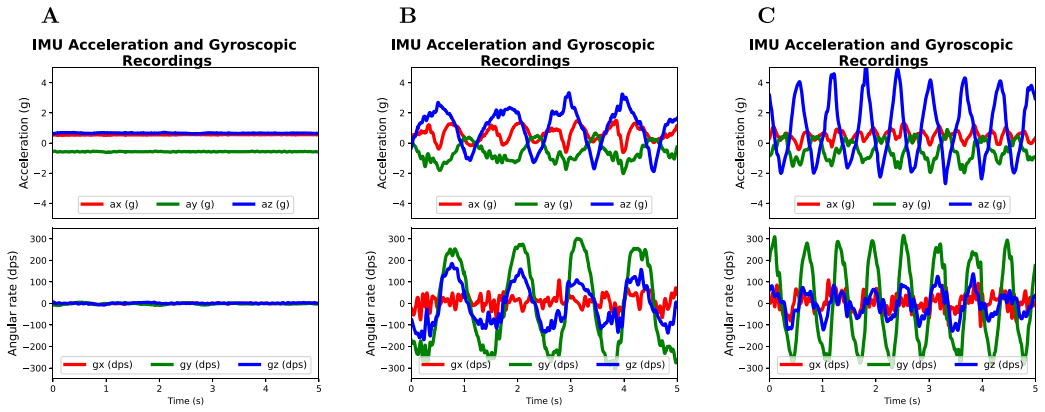
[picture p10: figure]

Fig. 5. IMU recordings during three scenarios; panel A, under no motion; panel B, during repetitive hand up-and-down motion at a frequency of 50 bpm; panel C, during repetitive hand up-and-down motion at a frequency of 100 bpm.

### 7.3. Multi-modal physiological data acquisition

To demonstrate TinZr’s capability to serve as a central hub interfacing with external physiological sensing modules for multimodal physiological sensing, electrocardiography (ECG) and photoplethysmography (PPG) signals were measured simultaneously. The ECG signal was collected from a custom single-lead ECG front-end based on the MAX30001 [31], while red and infrared PPG signals were collected from the MAX30102 [29,30] optical sensor. Both external sensing modules interfaced directly with the TinZr platform for data acquisition and wireless transmission. The MAX30102 and MAX30001 were selected as representative examples, and TinZr can also interface with other compatible external physiological sensing modules.
During the recording, TinZr acquired the ECG and dual-wavelength PPG signals concurrently and transmitted the data wirelessly (via BLE) for visualization and storage. Because the sensors operate at different native sampling rates, the data streams were packetized using a common transmission framework in which each packet included timing and sample-counter information. This allowed the received signals to be aligned during post-processing and enabled simultaneous visualization of ECG, red and infrared PPG waveforms.
Fig. 6 shows a representative 10 s recording of simultaneously acquired physiological signals. The blue ECG trace exhibits periodic cardiac cycles with distinguishable QRS complexes, while the red and infrared PPG signals shown as red and black traces, show waveforms corresponding to peripheral blood volume changes. This example showcases the TinZr’s ability as a multi-modal physiological data acquisition platform.

### 7.4. Power consumption and battery life

Power consumption was characterized under representative TinZr operating modes to estimate battery life during standby, wireless communication, and physiological signal acquisition. Current was measured manually using an ammeter connected in series between the TinZr board and a 150 mAh single-cell Li-Po battery. Estimated battery runtime was calculated by dividing the battery capacity (150 mAh) by the measured average current consumption (mA). We characterized the power consumption and estimated runtime for the following modes:

(1) Sleep Idle: In the sleep Idle condition, TinZr remained powered with Wi-Fi, BLE communication, sensor acquisition, and data streaming disabled, while the ESP32-C3 was placed in deep sleep without periodic wakeups. This condition represents the minimum standby current of the device when sensing and wireless communication are inactive.
(2) Active Idle: In the active Idle condition, TinZr remained powered with the ESP32-C3 CPU active, while Wi-Fi, BLE communication, sensor acquisition, and data streaming were disabled. This condition represents the baseline current draw of the powered device before enabling wireless communication or physiological signals sensing.
(3) BLE Advertising: In the BLE advertising condition, TinZr enabled the BLE radio and periodically transmitted advertising packets to allow wireless discovery. Sensor acquisition and BLE data streaming were disabled, and no central device connection was used. This condition quantifies the additional current required for wireless discoverability relative to active Idle.
(4) BLE Streaming: In the BLE streaming condition without sensors, TinZr maintained a BLE connection and transmitted packets at fixed output rates of 50, 100, and 200 Hz. Sensor acquisition was disabled. This condition isolates the current contribution of BLE connected data transmission.

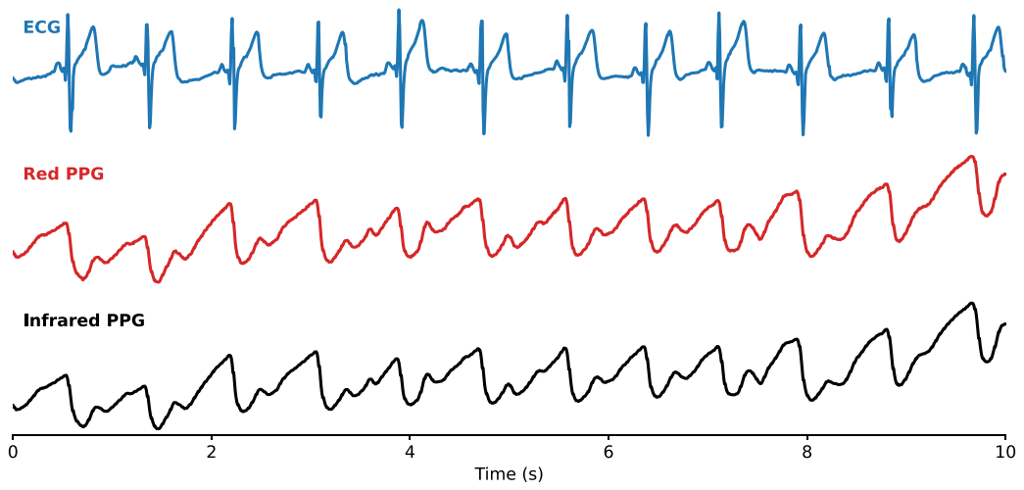
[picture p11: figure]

Fig. 6. Multi-modal physiological signals collected simultaneously. The ECG waveform, shown in blue, was acquired from a custom ECG front-end based on the MAX30001. Dual-wavelength PPG signals were acquired using a MAX30102 optical sensor, with the red PPG waveform shown in red and the infrared PPG waveform shown in black.

(5) BLE + MAX30102: In the PPG acquisition condition, TinZr streamed red and infrared PPG signals from the MAX30102 over BLE. Measurements were performed at 100 and 200 Hz to quantify the combined current contribution of optical sensing and BLE transmission.
(6) BLE + MAX30001: In the ECG acquisition condition, TinZr streamed a single-lead ECG waveform from the MAX30001 over BLE. Measurements were performed at 128 and 256 Hz to quantify the current required for ECG sensing and BLE streaming.
(7) BLE + MAX30102 + MAX30001: In the combined sensing condition, TinZr acquired PPG and ECG signals simultaneously and transmitted synchronized BLE packets. Because the sensors support different sampling rates, the BLE packet transmission rate was matched to the lower sensor rate for each configuration. Specifically, BLE packets were transmitted at 100 Hz when the MAX30102 and MAX30001 were sampled at 100 Hz and 128 Hz, respectively, and at 200 Hz when they were sampled at 200 Hz and 256 Hz, respectively.
(8) Wi-Fi Transmission: In the Wi-Fi transmission condition, BLE communication and sensor acquisition were disabled while TinZr connected to a Wi-Fi network and transmitted User Datagram Protocol (UDP) packets at 100 Hz. UDP was selected because it enabled continuous packet transmission at a fixed rate, providing a consistent and repeatable Wi-Fi workload for current consumption measurements. This condition represents the current required for active Wi-Fi-based wireless data transmission without physiological signals sensing.

Table 2 summarizes the average current drawn and the estimated runtime for the above-listed operating modes. Using a 150 mAh Li-Po battery, TinZr is capable of acquiring and wirelessly transmitting continuous multi-modal physiological data from connected sensing modules, which is desirable for research applications requiring physiological or other sensor measurements. The battery capacity should be selected based on the expected recording duration, as longer sessions may require a higher-capacity battery. TinZr also supports battery-voltage monitoring through the bat-lvl input, allowing users to implement a low-battery warning or automatic recording stop in the firmware. The battery used in this study also includes protection circuitry that disconnects the battery near the end of discharge [28].
The 3.3 V rail is generated by an AP2112K-3.3TRG1 low-dropout regulator, which has a maximum output current of 600 mA. Because this rail also powers the ESP32-C3 and onboard peripherals, the current available to external sensors depends on the operating configuration. More current may be available when power-intensive functions such as Wi-Fi or BLE are not used. As a conservative recommendation, we suggest limiting the combined continuous external load to 50 mA. Higher external loads may be supported depending on the active TinZr functions and the overall system configuration, while sensors requiring more current than TinZr can provide may require a separate external regulated power source.

### 7.5. Wireless communication characterization

Wireless communication performance was characterized to evaluate the practical reliability of TinZr BLE data transmission as an integrated wearable system. Although BLE communication is provided by the ESP32-C3 microcontroller, the practical wireless performance of TinZr also depends on the board layout, antenna placement, enclosure, firmware implementation, receiver hardware,

Table 2
Measured battery current consumption and estimated battery life under representative TinZr operating modes. Estimated runtime was calculated for a 150 mAh single-cell Li-Po battery.
Mode | Sensor configuration | Sampling rate | Battery current | Estimated runtime
Sleep Idle | None | – | 0.376 mA | 16.6 days
Active Idle | None | – | 14.8 mA | 10.14 h
BLE Advertising | None | – | 42.2 mA | 3.55 h
BLE Streaming | None | 50 Hz | 40.8 mA | 3.68 h
BLE Streaming | None | 100 Hz | 41.1 mA | 3.65 h
BLE Streaming | None | 200 Hz | 41.6 mA | 3.61 h
BLE + MAX30102a | Red and infrared PPG | 100 Hz | 47.9 mA | 3.13 h
BLE + MAX30102 | Red and infrared PPG | 200 Hz | 51.7 mA | 2.90 h
BLE + MAX30001b | Single ECG lead | 128 Hz | 50.2 mA | 2.99 h
BLE + MAX30001 | Single ECG lead | 256 Hz | 51.7 mA | 2.90 h
BLE + MAX30102 + MAX30001 | 100 Hz/128 Hz | 100 Hz | 56.5 mA | 2.65 h
BLE + MAX30102 + MAX30001 | 200 Hz/256 Hz | 200 Hz | 61.0 mA | 2.46 h
Wi-Fi Transmission | None | UDP, 100 Hz | 93.0 mA | 1.61 h

a We collect red and infrared PPG signals are collected from the MAX30102 sensor.
b We collect a single lead ECG waveform from a custom MAX30001-based board.

Table 3
Practical BLE wireless connectivity characterization of TinZr. All tests were performed for 180 s. Single-device tests were performed at 100 Hz, and multi-device tests were performed using five TinZr devices at 10 Hz per device.
Condition | No. Devices | Distance | Sampling rate | Packets expected | Packet loss | RSSI
| | (ft) | (Hz) | | (%) | (dBm)
Direct LOS | 1 | < 1 to 20 | 100 | 18,000 | 0 | −59.93 to −89.54
One Door | 1 | < 1 to 20 | 100 | 18,000 | 0 | −62.89 to −88.80
Direct LOS | 5 | < 1 to 20 | 10 | 9000 | 0 | −68.03 to −87.75
One Door | 5 | < 1 to 20 | 10 | 9000 | 0 | −68.41 to −88.04

and operating environment. Therefore, the goal of this experiment was not to revalidate the ESP32-C3 wireless specification, but rather to quantify the functional BLE performance of TinZr under representative real-life conditions.
Two BLE characterization tests were performed. The first test evaluated single-device high-rate transmission, typically used for physiological data acquisition from a wearable sensor. The second test evaluated simultaneous multi-device coordination, used in applications where multiple TinZr devices are used together, such as collaborative robotics.
For both tests, TinZr devices continuously transmitted BLE data packets to a laptop receiver running a custom Python application. Each transmitted BLE packet contained a device identifier, packet counter, timestamp, and representative dummy sample frames to emulate continuous data streaming. The receiver logged all received packets and used the packet counter sequence to identify missing data. Packet loss was calculated as the difference between the expected number of packets and the number of packets received, divided by the expected number of packets and expressed as a percentage. The received signal strength indicator (RSSI) was also recorded to provide a practical measure of the signal’s quality. All wireless tests were performed for 180 s, and the reported results represent the average values over the test duration. A detailed description of the two tests is as follows:
(1) In the single-device test, one TinZr device transmitted continuously at 100 Hz; a rate suitable for physiological data acquisition from wearable sensors. The device was placed at distances of <1 ft, 5 ft, 10 ft, 15 ft, and 20 ft from the laptop receiver. Measurements were performed under direct line-of-sight (LOS) conditions and with one-door separation, where the TinZr was positioned behind a wooden door relative to the receiver. This test evaluated whether TinZr could maintain reliable high-rate BLE transmission over practical indoor distances.
(2) In the multi-device test, five TinZr devices transmitted simultaneously to the same laptop receiver at 10 Hz per device using the same BLE packet format used in the first test. The lower per-device rate was selected to represent multi-TinZr coordination scenarios, such as collaborative or swarm robotics, where each TinZr transmits lower-rate state information such as position, motion, or status rather than continuous high-rate physiological waveforms. Multi-device tests were performed under similar distances and conditions.

Across the single-device test, TinZr maintained continuous BLE transmission with no observed packet loss for all distances (from <1 ft to 20 ft) under both direct LOS and one-door conditions. RSSI decreased with increasing distance and obstruction, as expected, but remained sufficient to maintain the BLE connection and data stream throughout the 180 s trials. In the multi-device test, the five TinZr devices were able to stream simultaneously to the laptop receiver, demonstrating practical multi-node operation under the tested conditions. Table 3 summarizes the practical BLE characterization results, including the number of TinZr devices, distance, sampling rate, expected packets, packet loss, and RSSI.

CRediT authorship contribution statement

Ludvik Alkhoury: Conceptualization, Methodology, Software, Validation, Investigation, Data curation, Writing – original draft, Writing – review & editing. Tony Moore: Conceptualization, Resources, Visualization, Writing – review & editing. Petras Swissler: Resources, Visualization, Writing – review & editing. N. Jeremy Hill: Resources, Visualization, Writing – review & editing. Sudhin A. Shah: Resources, Visualization, Writing – review & editing. Moshe Kam: Resources, Visualization, Funding acquisition, Supervision, Writing – review & editing.

Ethics statement

The data collection from the participant reported in Section 7.2 was approved by Weill Cornell Medicine Institutional Review Board (WCM-IRB) (IRB number 19-05020070). The study was conducted in accordance with the local legislation and institutional requirements. Written informed consent was obtained by the participants’ legal guardians/next of kin.

Declaration of competing interest

Ludvik Alkhoury, N. Jeremy Hill, and Sudhin A. Shah hold equity in and serve as the founding team for Cognitive Signals Inc. These interests have been disclosed to the authors’ respective institutions and are managed in accordance with their conflict-of-interest policies. The remaining authors declare no competing interests.

Acknowledgments

This work was funded by the New Jersey Institute of Technology (NJIT), Office of the Dean, Newark College of Engineering (NCE). Author N. Jeremy Hill acknowledges support from the National Institutes of Health (NIH) (grant P41EB018783), from NY State SCIRB (C37714GG-IDEA and C41212GM-IDEA), and from the Stratton VA Medical Center.

References

[1] Jayraj V. Vaghasiya, Carmen C. Mayorga-Martinez, Martin Pumera, Wearable sensors for telehealth based on emerging materials and nanoarchitectonics, Npj Flex. Electron. 7 (1) (2023) 26. (http://refhub.elsevier.com/S2468-0672(26)00101-X/sb1)
[2] Straits Research, Wearable sensors market size and outlook, 2025–2033, 2024, https://straitsresearch.com/report/wearable-sensors-market. (Accessed 12 October 2025).
[3] Bradley J. Petek, Mostafa A. Al-Alusi, Nathaniel Moulson, Aubrey J. Grant, Cyril Besson, J. Sawalla Guseh, Meagan M. Wasfy, Vincent Gremeaux, Timothy W. Churchill, Aaron L. Baggish, Consumer wearable health and fitness technology in cardiovascular medicine: JACC state-of-the-art review, J. Am. Coll. Cardiol. 82 (3) (2023) 245–264. (http://refhub.elsevier.com/S2468-0672(26)00101-X/sb3)
[4] Dhruv R. Seshadri, Ryan T. Li, James E. Voos, James R. Rowbottom, Celeste M. Alfes, Christian A. Zorman, Colin K. Drummond, Wearable sensors for monitoring the internal and external workload of the athlete, Npj Digit. Med. 2 (1) (2019) 71. (http://refhub.elsevier.com/S2468-0672(26)00101-X/sb4)
[5] Rory A. Cooper, George Smolinski, Jorge L. Candiotti, Shantanu Satpute, Garrett G. Grindle, Tawnee L. Sparling, Michelle J. Nordstrom, Xiaoning Yuan, Allison Symsack, Chang Dae Lee, et al., Current state, needs, and opportunities for wearable robots in military medical rehabilitation and force protection, in: Actuators, vol. 13, MDPI, 2024, p. 236. (http://refhub.elsevier.com/S2468-0672(26)00101-X/sb5)
[6] Patrik Kutilek, Petr Volf, Slavka Viteckova, Pavel Smrcka, Vaclav Krivanek, Lenka Lhotska, Karel Hana, Radek Doskocil, Leos Navratil, Zdenek Hon, et al., Wearable systems for monitoring the health condition of soldiers: Review and application, in: Proceedings of the International Conference on Military Technologies, ICMT, IEEE, 2017, pp. 748–752. (http://refhub.elsevier.com/S2468-0672(26)00101-X/sb6)
[7] Che-Chang Yang, Yeh-Liang Hsu, A review of accelerometry-based wearable motion detectors for physical activity monitoring, Sensors 10 (8) (2010) 7772–7788. (http://refhub.elsevier.com/S2468-0672(26)00101-X/sb7)
[8] Ludvik Alkhoury, JiWon Choi, Vishnu D. Chandran, Gabriela B. de Carvalho, Saikat Pal, Moshe Kam, Dual-wavelength photoplethysmography framework for heart rate calculation, Sensors 22 (24) (2022) 9955. (http://refhub.elsevier.com/S2468-0672(26)00101-X/sb8)
[9] Ludvik Alkhoury, Ji-Won Choi, Chizhong Wang, Arjun Rajasekar, Sayandeep Acharya, Sean Mahoney, Barry S. Shender, Leonid Hrebien, Moshe Kam, Heart-rate tuned comb filters for processing photoplethysmogram (PPG) signals in pulse oximetry, J. Clin. Monit. Comput. 35 (4) (2021) 797–813. (http://refhub.elsevier.com/S2468-0672(26)00101-X/sb9)
[10] Mohamed Adel Serhani, Hadeel T. El Kassabi, Heba Ismail, Alramzana Nujum Navaz, ECG monitoring systems: Review, architecture, processes, and key challenges, Sensors 20 (6) (2020) 1796. (http://refhub.elsevier.com/S2468-0672(26)00101-X/sb10)
[11] Burcu Arman Kuzubasoglu, Ersin Sayar, Cedric Cochrane, Vladan Koncar, Senem Kursun Bahadir, Wearable temperature sensor for human body temperature detection, J. Mater. Sci., Mater. Electron. 32 (4) (2021) 4784–4797. (http://refhub.elsevier.com/S2468-0672(26)00101-X/sb11)
[12] Ziao Xue, YanSong Gai, Yuxiang Wu, Zhuo Liu, Zhou Li, Wearable mechanical and electrochemical sensors for real-time health monitoring, Commun. Mater. 5 (1) (2024) 211. (http://refhub.elsevier.com/S2468-0672(26)00101-X/sb12)
[13] Rahul K. Kher, Dipak M. Patel, A comprehensive review on wearable health monitoring systems, Open Biomed. Eng. J. 15 (1) (2021). (http://refhub.elsevier.com/S2468-0672(26)00101-X/sb13)
[14] Louis J. Dankovich, Janell S. Joyner, William He, Ahmad Sesay, Monifa Vaughn-Cooke, CogWatch: An open-source platform to monitor physiological indicators for cognitive workload and stress, HardwareX 19 (2024). (http://refhub.elsevier.com/S2468-0672(26)00101-X/sb14)
[15] Adafruit Industries LLC, Adafruit QT Py ESP32-S2 WiFi dev board (product ID: 5325), 2022, https://www.adafruit.com/product/5325. (Accessed 13 October 2025).
[16] Tommaso Polonelli, Lukas Schulthess, Philipp Mayer, Michele Magno, Luca Benini, H-watch: An open, connected platform for AI-enhanced COVID-19 symptom monitoring and contact tracing, in: Proceedings of the IEEE International Symposium on Circuits and Systems, ISCAS, IEEE, 2021, pp. 1–5. (http://refhub.elsevier.com/S2468-0672(26)00101-X/sb16)
[17] Sebastian Frey, Giusy Spacone, Andrea Cossettini, Marco Guermandi, Philipp Schilk, Luca Benini, Victor Kartsch, BioGAP-ultra: A modular edge-AI platform for wearable multimodal biosignal acquisition and processing, 2025, arXiv preprint arXiv:2508.13728. (http://arxiv.org/abs/2508.13728)
[18] Gabriel P.M. Pinheiro, Ricardo K. Miranda, Bruno J.G. Praciano, Giovanni A. Santos, Fábio L.L. Mendonça, Elnaz Javidi, João Paulo da Costa, Jr. de Sousa, Multi-sensor wearable health device framework for real-time monitoring of elderly patients using a mobile application and high-resolution parameter estimation, Front. Hum. Neurosci. 15 (2022) 750591. (http://refhub.elsevier.com/S2468-0672(26)00101-X/sb18)
[19] Texas Instruments, CC2640R2F SimpleLink Bluetooth Low Energy wireless MCU, 2020, https://www.ti.com/product/CC2640R2F. (Accessed 13 October 2025).

[20] Seeed Studio, Getting started with Seeed Studio XIAO ESP32C3, 2024, https://wiki.seeedstudio.com/XIAO_ESP32C3_Getting_Started/. (Accessed 13 October 2025).
[21] Amazon, ESP32-C3 mini development board, 2025, https://www.amazon.com/ESP32-C3-Development-Bluetooth-Single-Core-Processor/dp/B0D5XNBPBC?th=1. (https://www.amazon.com/ESP32-C3-Development-Bluetooth-Single-Core-Processor/dp/B0D5XNBPBC?th=1) (Accessed 13 October 2025).
[22] DFRobot, Beetle ESP32-C6 mini development board, 2025, https://www.dfrobot.com/product-2778.html. (Accessed 13 October 2025).
[23] Adafruit Industries LLC, GEMMA v2 — miniature wearable electronic platform (product ID: 1222), 2025, https://www.adafruit.com/product/1222. (Accessed 13 October 2025).
[24] PJRC, Teensy 4.1 development board, 2025, https://www.pjrc.com/store/teensy41.html. (Accessed 13 October 2025).
[25] EasyEDA Team, EasyEDA: Online PCB design tool, 2024, https://easyeda.com/. (Accessed 13 August 2024).
[26] KiCad Development Team, Kicad EDA, 2024, https://www.kicad.org/. (Accessed 15 August 2024).
[27] FreeCAD Community, FreeCAD: Your own 3D parametric modeler, 2024, https://www.freecad.org/. (Accessed 15 August 2024).
[28] Adafruit Industries LLC, Lithium ion polymer battery — 3.7V 150mAh (product ID: 1317), 2026, https://www.adafruit.com/product/1317. (Accessed 12 January 2026).
[29] Analog Devices, MAX30102: High-Sensitivity Pulse Oximeter and Heart-Rate Sensor for Wearable Health, 2018, Rev. 1, November 8, 2018. https: //www.analog.com/media/en/technical-documentation/data-sheets/max30102.pdf. (Accessed 12 January 2026).
[30] AEDIKO, MAX30102 heart rate sensor module (2-pack), 2026, https://www.amazon.com/AEDIKO-MAX30102-Detection-Concentration-Compatible/dp/B09LQDW27N. (https://www.amazon.com/AEDIKO-MAX30102-Detection-Concentration-Compatible/dp/B09LQDW27N) (Accessed 12 January 2026).
[31] Analog Devices, MAX30001: Ultra-Low-Power, Single-Channel Integrated Biopotential (ECG, R-to-R, and Pace Detection) and Bioimpedance (BioZ) Analog Front End, 2019, Rev. 3, September 9, 2019. https://www.analog.com/media/en/technical-documentation/data-sheets/max30001.pdf. (Accessed 12 January 2026).

Ludvik Alkhoury is a postdoctoral associate of radiology at Weill Cornell Medicine. He received a B.S. in electrical engineering from the University of Balamand (UOB), Lebanon. He then joined the Data Fusion Lab (directed by Professor Moshe Kam) at the New Jersey Institute of Technology (NJIT) in 2018. In 2023, he received a Ph.D. in electrical engineering from the Helen and John C. Hartmann Department of Electrical and Computer Engineering at NJIT. His doctoral research focused on wearable health monitoring sensors and methods to extract non-invasive high-quality vital signs (such as heart rate and oxygen saturation) during extensive human motion. He is currently working in Dr. Sudhin Shah’s laboratory to study the brain’s response to language in children and adults with brain injuries.

Tony Moore is a design engineer with Mortronics Ltd. Ireland. He received a B.Sc. in Experimental Physics from University College Dublin in 1976. He worked in Medical Physics until 1986, then spent 25 years designing components for burglar alarm systems. In 2012 set up Mortronics and has worked in design consultancy for different sectors.

Petras Swissler is an assistant professor in the Department of Mechanical and Industrial Engineering at the New Jersey Institute of Technology (NJIT). He received his B.S. in Mechanical engineering from the Rose-Hulman Institute of Technology in 2012, after which he pursued a career in the aerospace industry. He returned to graduate school to pursue his interest in swarm robotics and received his Ph.D. in Mechanical Engineering in 2022 from Northwestern University and joined the faculty of NJIT that same year. His research at NJIT focuses on achieving biological-scale swarm robotic systems and pursuing their applications to real-world problems.

Jeremy Hill is a Senior Research Scientist and Director of Clinical Systems Development at the National Center for Adaptive Neurotechnologies, Stratton VA Medical Center in Albany, NY, and an Affiliate Professor at the Electrical & Computer Engineering Dept. of the State University of New York at Albany. He completed his bachelor, masters and doctoral degrees at the Department of Experimental Psychology at the University of Oxford, UK. He has also worked as a research scientist at the Max Planck Institute for Biological Cybernetics, at New York State’s Wadsworth Center, and at the Burke Neurological Institute. He has 30 years’ experience of research and development at the confluence of neuroscience, statistics, machine-learning, and software engineering, a driving interest in neural-engineering applications that improve the lives of people with neurological injuries and disorders, and a passion for making usable, re-usable tools for neuroscience.

Sudhin Shah, Ph.D., is an associate professor of neuroscience in the department of radiology within the Brain Health and Imaging Institute at Weill Cornell Medicine (WCM). She received her B.Sc. in electrical engineering from Drexel University followed by a M.Sc. in biomedical engineering from Columbia University. She received her Ph.D. in systems neuroscience from the Weill Cornell Graduate School of Medical Sciences at Cornell University. She completed her postdoctoral training at WCM as well. Dr. Shah is also the Scientific Director of cognitive recovery research at Blythedale Children’s Hospital. She is an affiliate faculty member with the Consortium for the Advanced Study of Brain Injury at WCM. She has served on several National Institutes of Health scientific review panels, and as an invited reviewer for several journals. She has also served as a research mentor for more than 10 medical and graduate students.

Moshe Kam is an engineering educator and researcher, serving as Distinguished Professor and Dean of the Newark College of Engineering at the New Jersey Institute of Technology. Until August 2014, he served as the Robert G. Quinn Professor and department head of electrical and computer engineering at Drexel University. In 2011, he served concurrently as the 49th president and CEO of IEEE. Earlier, he was IEEE’s vice president for educational activities (2005–2007) and IEEE’s representative director to the accreditation body ABET. Kam is known for his studies of decision fusion and distributed detection, which focus on computationally feasible fusion rules for multi-sensor systems.

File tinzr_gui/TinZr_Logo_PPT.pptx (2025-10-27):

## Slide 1

TinZr

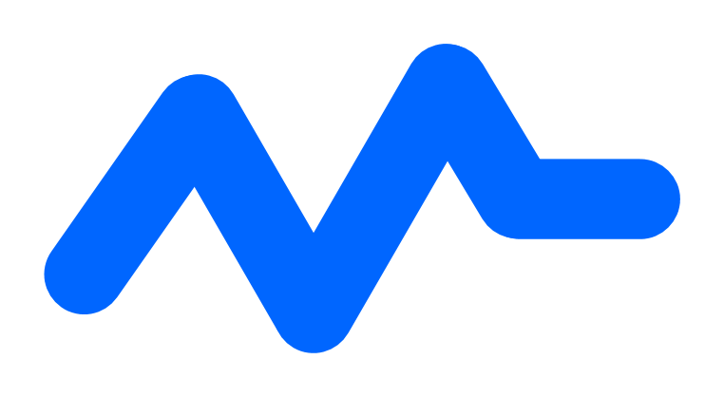
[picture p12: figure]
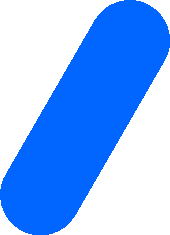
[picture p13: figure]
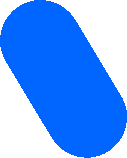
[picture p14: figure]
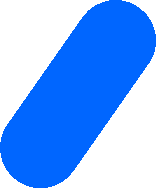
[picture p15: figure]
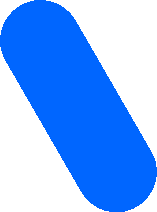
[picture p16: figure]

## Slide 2

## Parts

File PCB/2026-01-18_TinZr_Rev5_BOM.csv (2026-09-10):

No. | Quantity | Comment | Designator | Footprint | Value | Manufacturer Part | Manufacturer | Supplier Part | Supplier
1 | 1 | 2450AT18D0100E | ANT2 | ANT-SMD_4P-L3.2-W1.6 |  | 2450AT18D0100E | JOHANSON(约翰逊) | C2917718 | LCSC
2 | 2 | 10uF | C3,C12 | c0402 | 10uF | CL05A106MP5NUNC | SAMSUNG(三星) | C315248 | LCSC
3 | 7 | 100nF | C4,C5,C6,C24,C25,C26,C28 | c0402 | 100nF | CL05B104KO5NNNC | SAMSUNG(三星) | C1525 | LCSC
4 | 3 | 1uF | C7,C8,C14 | c0402 | 1uF | CL05A105KA5NQNC | SAMSUNG(三星) | C52923 | LCSC
5 | 1 | 10nF | C9 | c0402 | 10nF | CL05B103KB5NNNC | SAMSUNG(三星) | C15195 | LCSC
6 | 2 | 22pF | C10,C11 | c0402 | 22pF | 0402CG220J500NT | FH(风华) | C1555 | LCSC
7 | 1 | 1uF | C16 | C0402 | 1uF | LMK105BJ105KV-F | TAIYO YUDEN(太诱) | C87145 | LCSC
8 | 1 | 10uF | C18 | C0805 | 10uF | CL21A106KAYNNNE | SAMSUNG(三星) | C15850 | LCSC
9 | 4 | 4.7uF | C21,C27,C29,C33 | C0603 | 4.7uF | CL10A475KO8NNNC | SAMSUNG(三星) | C1705 | LCSC
10 | 1 | 2pF | C34 | C0402 | 2pF | CGA2B2NP01H020C050BA | TDK | C2181699 | LCSC
11 | 1 | 1.0T-4P卧贴 | CN1 | CONN-SMD_1.0T-4P |  | 1.0T-4P卧贴 | BOOMELE(博穆精密) | C145956 | LCSC
12 | 1 | 1N5819HW-7-F | D1 | SOD-123_L2.7-W1.6-LS3.7-RD |  | 1N5819HW-7-F | DIODES(美台) | C82544 | LCSC
13 | 1 | 2nH | L4 | L0603 | 2nH | SDCL1608C2N0STDF | Sunlord(顺络) | C370234 | LCSC
14 | 1 | WS2812C-2020-V1 | LED3 | LED-SMD_4P-L2.0-W2.0-TL_WS2812B-2020 |  | WS2812C-2020-V1 | worldsemi | C2976072 | LCSC
15 | 1 | XL-1005UGC | LED5 | LED0402-RD_GREEN |  | XL-1005UGC | XINGLIGHT(成兴光) | C965793 | LCSC
16 | 8 | 10kΩ | R11,R19,R20,R25,R26,R27,R58,R61 | r0402 | 10kΩ | 0603WAF1002T5E | UNI-ROYAL(厚声) | C25804 | LCSC
17 | 1 | 10kΩ | R17 | R0603 | 10kΩ | 0603WAF1002T5E | UNI-ROYAL(厚声) | C25804 | LCSC
18 | 1 | 100Ω | R28 | R0402 | 100Ω | RC0402FR-07100RL | YAGEO(国巨) | C106232 | LCSC
19 | 1 | 0Ω | R29 | R0402 | 0Ω | RC0402JR-070RL | YAGEO(国巨) | C60485 | LCSC
20 | 1 | 220kΩ | R30 | R0402 | 220kΩ | RC0402JR-07220KL | YAGEO(国巨) | C137900 | LCSC
21 | 1 | 150kΩ | R31 | R0402 | 150kΩ | FRC0402F1503TS | FOJAN(富捷) | C2909320 | LCSC
22 | 8 | 33Ω | R44,R48,R49,R50,R59,R60,R62,R63 | R0402 | 33Ω | 0402WGF330JTCE | UNI-ROYAL(厚声) | C25105 | LCSC
23 | 1 | 46.4kΩ | R57 | R0402 | 46.4kΩ | RC0402FR-0746K4L | YAGEO(国巨) | C185412 | LCSC
24 | 2 | 2kΩ | R64,R65 | R0402 | 2kΩ | 0402WGF2001TCE | UNI-ROYAL(厚声) | C4109 | LCSC
25 | 1 | 8.2kΩ | R66 | R0402 | 8.2kΩ | RC0402FR-078K2L | YAGEO(国巨) | C137929 | LCSC
26 | 1 | 3kΩ | R67 | R0402 | 3kΩ | RC0402FR-073KL | YAGEO(国巨) | C137987 | LCSC
27 | 1 | 1040310811 | SIM1 | SIM-SMD_8P-1040310811 |  | 1040310811 | MOLEX | C585350 | LCSC
28 | 1 | SKRPABE010 | SW2 | KEY-SMD_4P-L4.2-W3.2-P2.20-LS4.6 |  | SKRPABE010 | ALPSALPINE(阿尔卑斯阿尔派) | C115360 | LCSC
29 | 1 | ESP32-C3FH4 | U1 | QFN-32_L5.0-W5.0-P0.50-TL-EP3.7 |  | ESP32-C3FH4 | ESPRESSIF(乐鑫) | C2858491 | LCSC
30 | 1 | 40MHz | U4 | CRYSTAL-SMD_4P-L2.0-W1.6-BL_7D026000M01 | 40MHz | X252040MMB4SI | YXC(扬兴晶振) | C2885592 | LCSC
31 | 3 | LESD5D5.0CT1G | U12,U13,U14 | SOD-523_L1.2-W0.8-LS1.6-BI |  | LESD5D5.0CT1G | Leiditech(雷卯电子) | C5246195 | LCSC
32 | 1 | AP2112K-3.3TRG1 | U16 | SOT-23-5_L2.9-W1.6-P0.95-LS2.8-BR |  | AP2112K-3.3TRG1 | TECH PUBLIC(台舟) | C23380830 | LCSC
33 | 1 | TL1014AF220QG | U18 | SW-SMD_E-SWITCH_TL1014AFXXX |  | TL1014AF220QG | E-Switch | C4364321 | LCSC
34 | 1 | LSM6DS3TR-C | U19 | LGA-14_L3.0-W2.5-P0.50-TL |  | LSM6DS3TR-C | ST(意法半导体) | C967633 | LCSC
35 | 1 | XL-1005UWC | U22 | LED0402-RD_YELLOW |  | XL-1005UWC | XINGLIGHT(成兴光) | C20613596 | LCSC
36 | 1 | BQ24075RGTR | U23 | QFN-16_L3.0-W3.0-P0.50-TL-EP1.7 |  | BQ24075RGTR | TI(德州仪器) | C15464 | LCSC
37 | 1 | MicroXNJ | USB2 | MICRO-USB-SMD_MICROXNJ_1 |  | MicroXNJ | SHOU HAN(首韩) | C404969 | LCSC

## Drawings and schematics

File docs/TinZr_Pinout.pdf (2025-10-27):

# Top Layer

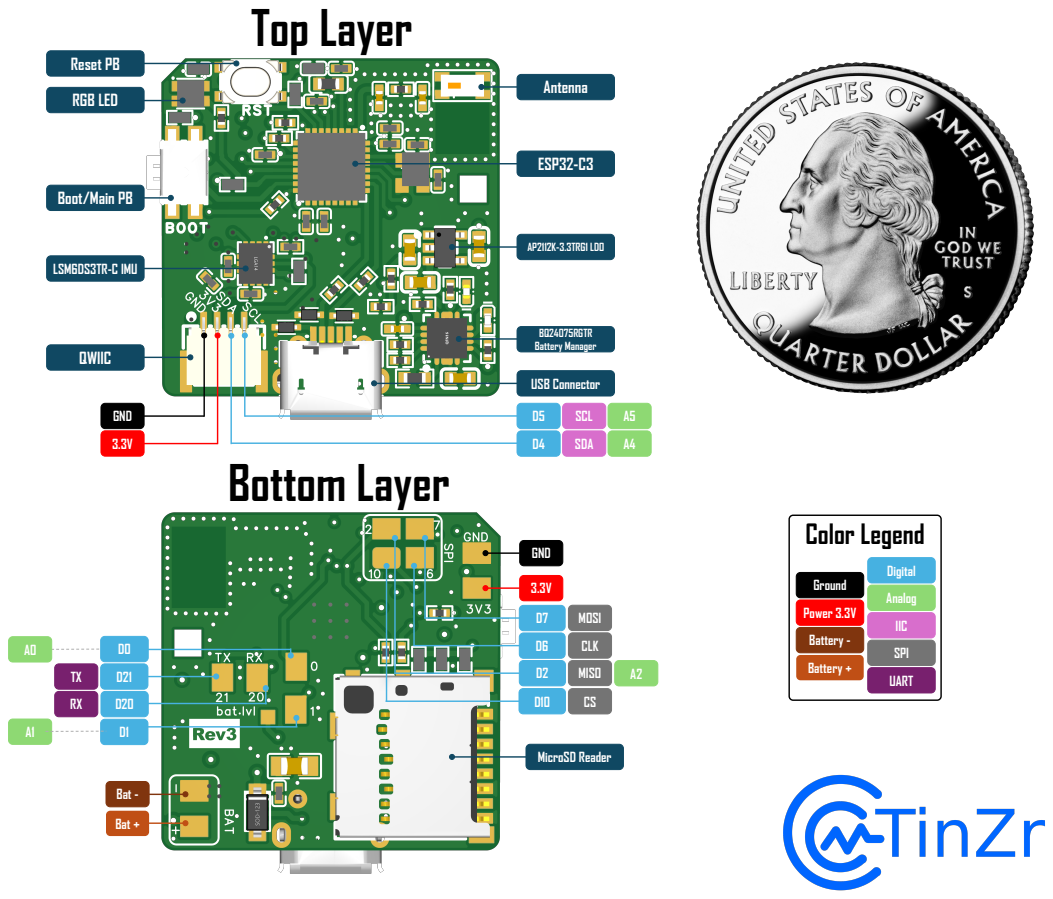
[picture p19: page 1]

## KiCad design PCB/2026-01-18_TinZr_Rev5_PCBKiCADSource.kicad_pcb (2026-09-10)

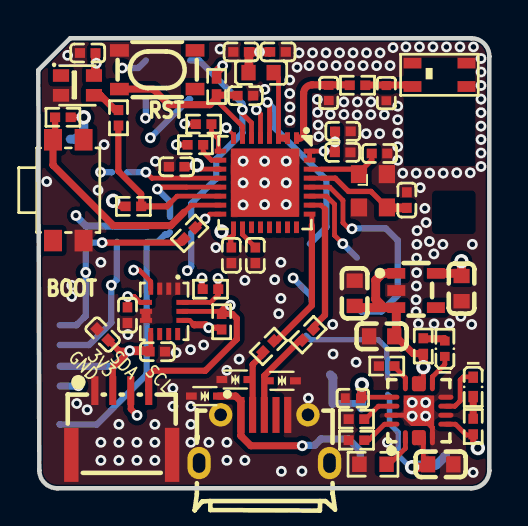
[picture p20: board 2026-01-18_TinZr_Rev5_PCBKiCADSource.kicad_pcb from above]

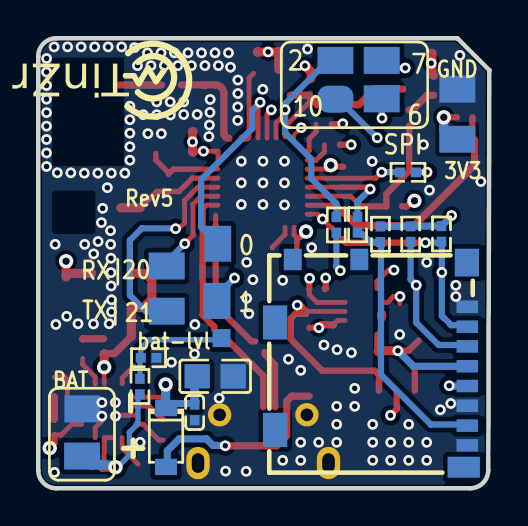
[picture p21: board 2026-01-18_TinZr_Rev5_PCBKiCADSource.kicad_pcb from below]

Board: 4 copper layers, 25.1 x 25.0 mm, 68 parts (12 on the bottom side), 42 nets.

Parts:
ANT2: ANT-SMD_4P-L3.2-W1.6
C3, C4, C5, C6, C7, C8, C9, C10, C11, C12, C14, C24, C25, C26, C28: c0402
C16, C31, C34: C0402
C18: C0805
C21, C27, C29, C33: C0603
CN1: CONN-SMD_1.0T-4P
D1: SOD-123_L2.7-W1.6-LS3.7-RD
L4: L0603
LED3: LED-SMD_4P-L2.0-W2.0-TL_WS2812B-2020
LED5: LED0402-RD_GREEN
R11, R19, R20, R25, R26, R27, R58, R61: r0402
R17: R0603
R28, R29, R30, R31, R44, R48, R49, R50, R57, R59, R60, R62, R63, R64, R65, R66, R67: R0402
SIM1: SIM-SMD_8P-1040310811
SW2: KEY-SMD_4P-L4.2-W3.2-P2.20-LS4.6
U1: QFN-32_L5.0-W5.0-P0.50-TL-EP3.7
U4: CRYSTAL-SMD_4P-L2.0-W1.6-BL_7D026000M01
U12, U13, U14: SOD-523_L1.2-W0.8-LS1.6-BI
U16: SOT-23-5_L2.9-W1.6-P0.95-LS2.8-BR
U18: SW-SMD_E-SWITCH_TL1014AFXXX
U19: LGA-14_L3.0-W2.5-P0.50-TL
U22: LED0402-RD_YELLOW
U23: QFN-16_L3.0-W3.0-P0.50-TL-EP1.7
USB2: MICRO-USB-SMD_MICROXNJ_1

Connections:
$1N1048: L4.2, U1.2, U1.3
$1N1429: C7.2, U1.18
$1N2460: C31.2, R29.2, U1.1
$1N25832: D1.2, U12.2, USB2.1
$1N25847: R59.1, U13.2, USB2.2
$1N25849: R60.1, U14.2, USB2.3
$1N31251: ANT2.1, C34.2, R29.1
$1N47755: LED3.3, R28.2
$1N85064: R26.2, R50.1, SIM1.7
$1N94189: U22.1, U23.7
$1N94195: LED5.1, U23.9
$1N94200: R17.2, U23.1
$1N94207: R57.2, U23.14
$1N94553: R27.1, R48.2, SIM1.3
$1N94607: R49.1, SIM1.5
$1N94651: R25.2, R44.2, SIM1.2
$1N97194: R62.2, U1.9
$1N97235: R63.2, U1.10
$1N106267: LED5.2, R64.1
$1N106270: R65.1, U22.2
$1N126315: R66.2, U23.16
$1N126394: R67.2, U23.12
+3V3: C3.1, C4.2, C5.2, C6.2, C8.2, C9.2, C12.1, C21.2, C24.1, C25.1, C26.1, CN1.2, L4.1, LED3.4, R11.2, R19.2, R20.1, R25.1, R26.1, R27.2, R58.2, R61.2, SIM1.4, U1.11, U1.17, U1.31, U1.32, U16.5, U19.5, U19.8, U19.12
BAT+: C33.2, R30.2, U23.2, U23.3
BATTERY_V_LEVEL: R30.1, R31.2
BOOT/PB: R20.2, U1.15, U18.4
CHIP_EN: C14.2, R11.1, SW2.2, U1.7
D+: R60.2, U1.26
D-: R59.2, U1.25
GND: ANT2.2, ANT2.3, ANT2.4, C3.2, C4.1, C5.1, C6.1, C7.1, C8.1, C9.1, C10.2, C11.1, C12.2, C14.1, C16.1, C18.1, C21.1, C24.2, C25.2, C26.2, C27.1, C28.2, C29.1, C31.1, C33.1, C34.1, CN1.0, CN1.1, LED3.2, R17.1, R31.1, R57.1, R66.1, R67.1, SIM1.1, SIM1.6, SIM1.8, SW2.4, U1.33, U4.2, U4.4, U12.1, U13.1, U14.1, U16.2, U18.1, U19.1, U19.2, U19.3, U19.6, U19.7, U23.4, U23.6, U23.8, U23.15, U23.17, USB2.5, USB2.6, USB2.7, USB2.8, USB2.9
IMU_INT: U1.8, U19.4
POW: C27.2, C29.2, R64.2, R65.2, U16.1, U16.3, U23.5, U23.10, U23.11
RGB: R28.1, R58.1, U1.14
SCL: CN1.4, R61.1, R63.1, U19.13
SDA: CN1.3, R19.1, R62.1, U19.14
SD_CS: R44.1, U1.16
SPCLK: R49.2, U1.12
SPID/MOSI: R50.2, U1.13
SPIQ/MISO: R48.1, U1.6
VBUS: C16.2, C18.2, C28.1, D1.1, U23.13
XTAL_N: C10.1, U1.29, U4.3
XTAL_P: C11.2, U1.30, U4.1

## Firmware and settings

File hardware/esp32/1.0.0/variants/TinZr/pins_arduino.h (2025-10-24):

#ifndef Pins_Arduino_h
#define Pins_Arduino_h

#include <stdint.h>
#include "soc/soc_caps.h"

// ===== Built-in RGB (WS2812C) on GPIO8 =====
#define PIN_RGB_LED 8
#define PB_PIN 9

// Use a "virtual" builtin index so rgbLedWrite() works (not digitalWrite)
static const uint8_t LED_BUILTIN = SOC_GPIO_PIN_COUNT + PIN_RGB_LED;
#define BUILTIN_LED  LED_BUILTIN
#define RGB_BUILTIN  LED_BUILTIN
#define RGB_BRIGHTNESS 128   // 0–255 default

// ===== UART0 defaults (USB-CDC) =====
static const uint8_t TX = 21;
static const uint8_t RX = 20;

// ===== I2C defaults (avoid strap pins 8/9) =====
static const uint8_t SDA = 4;
static const uint8_t SCL = 5;
#define PIN_WIRE_SDA SDA
#define PIN_WIRE_SCL SCL

// ===== SPI defaults =====
static const uint8_t SS   = 10;
static const uint8_t MOSI = 2;
static const uint8_t MISO = 7;
static const uint8_t SCK  = 6;
#define PIN_SPI_SS   SS
#define PIN_SPI_MOSI MOSI
#define PIN_SPI_MISO MISO
#define PIN_SPI_SCK  SCK

// ===== Analog aliases (C3: ADC1=GPIO0..4, ADC2=GPIO5) =====
static const uint8_t A0 = 0;
static const uint8_t A1 = 1;
static const uint8_t A2 = 2;
static const uint8_t A3 = 255; // not available on this board
static const uint8_t A4 = 4;
static const uint8_t A5 = 5;   // ADC2; OK but has caveats vs ADC1

#endif /* Pins_Arduino_h */

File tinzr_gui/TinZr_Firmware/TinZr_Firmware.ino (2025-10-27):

/*
  TinZr legacy BLE firmware (RX command support; IMU+PPG normalized)
  - ESP32-C3 + classic ESP32 BLE (BLEDevice.h)
  - Service UUID:        4fafc201-1fb5-459e-8fcc-c5c9c331914b
  - Notify Characteristic beb5483e-36e1-4688-b7f5-ea07361b26a8  (TX -> App)
  - RX Characteristic     e7810a71-73ae-499d-8c15-faa9aef0c3f2  (App -> FW)

  Sends (when enabled):
    IMU,ax,ay,az,gx,gy,gz,temp
    PPG,ir,red,green
  Also sends:
    BAT,<volts>  (on boot, post-connect, periodic; and on READ_BAT)
*/

#include <Arduino.h>
#include <Wire.h>

// ========= Feature flags =========
#define FEAT_LED        1
#define FEAT_IMU        1
#define FEAT_PPG        1
#define FEAT_BATTERY    1
#define FEAT_SDLOG      0
#define FEAT_BUTTON_REC 0
// =================================

// -------- Pins & board specifics --------
#define PIN_RGB_LED  8      // NeoPixel data (GPIO8 on many C3 boards)
#define NUM_LEDS     1
#define VBAT_PIN     A1     // Battery divider input (top 220k -> VBAT, bottom 150k -> GND)
// If you enable FEAT_BUTTON_REC, define PB_PIN here (to GND, INPUT_PULLUP)
// #define PB_PIN    9

// Battery divider math
static const float VREF      = 3.3f;
static const float ADC_MAX   = 4095.0f; // ESP32-C3 12-bit
static const float DIV_RATIO = 150000.0f / (220000.0f + 150000.0f);  // ≈0.405

// ===== LED (NeoPixel) =====
#if FEAT_LED
  #include <Adafruit_NeoPixel.h>
  Adafruit_NeoPixel strip(NUM_LEDS, PIN_RGB_LED, NEO_GRB + NEO_KHZ800);

  uint8_t  gBrightness = 60;
  bool     gRainbow    = false;
  uint32_t gLastLedMs  = 0;
  uint8_t  gHue        = 0;

  static uint32_t Wheel(uint8_t pos) {
    if (pos < 85) return strip.Color(pos * 3, 255 - pos * 3, 0);
    if (pos < 170) { pos -= 85; return strip.Color(255 - pos * 3, 0, pos * 3); }
    pos -= 170; return strip.Color(0, pos * 3, 255 - pos * 3);
  }

  static void led_apply(uint8_t r, uint8_t g, uint8_t b) {
    strip.setPixelColor(0, strip.Color(r, g, b));
    strip.show();
  }

  static void led_set(uint8_t r, uint8_t g, uint8_t b){
    strip.setBrightness(gBrightness);
    led_apply(r, g, b);
  }

  static void led_brightness(uint8_t b){
    gBrightness = b;
    strip.setBrightness(gBrightness);
    strip.show();
  }
#endif

// ===== IMU =====
#if FEAT_IMU
  #include <Adafruit_LSM6DS3TRC.h>
  #include <Adafruit_Sensor.h>
  Adafruit_LSM6DS3TRC lsm6;
  bool     gIMUEnabled     = true;         // start ON for easy testing
  uint32_t gLastImuMs      = 0;
  uint32_t IMU_INTERVAL_MS = 100;          // 10 Hz (set ~25 for ~40 Hz)
  // latest
  float ax=0, ay=0, az=0;
  float gx=0, gy=0, gz=0;
  float tC=0;
#endif

// ===== PPG =====
#if FEAT_PPG
  #include "MAX30105.h"
  MAX30105 particleSensor;
  bool     gPPGEnabled      = true;        // start ON for easy testing
  uint32_t gLastPpgMs       = 0;
  uint32_t PPG_INTERVAL_MS  = 100;         // 10 Hz (set ~25 for ~40 Hz)
  const uint32_t NO_FINGER_THRESHOLD = 1000;
  // latest
  uint32_t ir=0, red=0, green=0;
#endif

// ===== Battery =====
#if FEAT_BATTERY
  uint32_t gLastBatMs = 0;
  const uint32_t BAT_INTERVAL_MS = 5UL * 60UL * 1000UL; // 5 minutes

  static float readVBat() {
    #if defined(analogSetPinAttenuation)
      analogSetPinAttenuation(VBAT_PIN, ADC_ATTEN_DB_11); // ~3.9V FS on ADC pin
    #endif
    uint32_t acc = 0; const int N = 16;
    for (int i=0;i<N;++i){ acc += analogRead(VBAT_PIN); delay(2); }
    float raw   = float(acc)/N;
    float v_div = raw * (VREF / ADC_MAX);
    return v_div / DIV_RATIO;
  }
#endif

// ===== SD logging (optional) =====
#if FEAT_SDLOG
  #include <SPI.h>
  #include <SD.h>
  bool gLogSD=false; File gSDFile; uint32_t gLastFileFlushMs=0;
  static String makeLogName(const char* base) {
    for (uint32_t i=0;i<100000;i++){ char n[24]; snprintf(n,sizeof(n),"/%s%05lu.CSV",base,(unsigned long)i);
      if(!SD.exists(n)) return String(n); }
    return String("/LOG.CSV");
  }
  static void sd_start(){
    if (gLogSD) return;
    if (!SD.begin(SS, SPI, 1000000)) { Serial.println(F("SD begin @1MHz FAIL")); return; }
    SD.end(); delay(50);
    if (!SD.begin(SS, SPI, 4000000)) { Serial.println(F("SD re-begin @4MHz FAIL, fallback 1MHz")); SD.begin(SS, SPI, 1000000); }
    String fn = makeLogName("LOG");
    gSDFile = SD.open(fn, FILE_WRITE);
    if (!gSDFile){ Serial.println(F("SD open FAIL")); return; }
    gSDFile.println(F("millis,source,vals"));
    gSDFile.flush();
    gLogSD = true; Serial.print(F("SD logging -> ")); Serial.println(fn);
  }
  static void sd_stop(){ if (!gLogSD) return; if (gSDFile){ gSDFile.flush(); gSDFile.close(); } gLogSD=false; }
  static void sd_append(const char* src, const String& csv){
    if (!gLogSD || !gSDFile) return;
    gSDFile.print(millis()); gSDFile.print(','); gSDFile.print(src); gSDFile.print(','); gSDFile.println(csv);
    if (millis() - gLastFileFlushMs > 1000){ gLastFileFlushMs = millis(); gSDFile.flush(); }
  }
#endif

// ======== CLASSIC ESP32 BLE (legacy profile) ========
#include <BLEDevice.h>
#include <BLEServer.h>
#include <BLEUtils.h>
#include <BLE2902.h>

// UUIDs (legacy)
#define SERVICE_UUID        "4fafc201-1fb5-459e-8fcc-c5c9c331914b"
// TX notify to app:
#define CHAR_TX_UUID        "beb5483e-36e1-4688-b7f5-ea07361b26a8"
// RX write from app:
#define CHAR_RX_UUID        "e7810a71-73ae-499d-8c15-faa9aef0c3f2"

BLEServer*         pServer     = nullptr;
BLECharacteristic* pNotifyChar = nullptr;
BLECharacteristic* pRxChar     = nullptr;
bool deviceConnected = false;

static String gCmdBuf;
volatile bool gJustConnected = false;

// --- helper: TX notify + Serial echo for debug ---
static void bleSendLine(const String& line){
  if (!pNotifyChar) return;
  std::string s = (line + "\n").c_str();
  pNotifyChar->setValue((uint8_t*)s.data(), s.size());
  if (deviceConnected) pNotifyChar->notify();
  Serial.print(F("TX ")); Serial.println(line);
}

class MyServerCallbacks : public BLEServerCallbacks {
  void onConnect(BLEServer* server) override {
    deviceConnected = true;
    gJustConnected = true;
  }
  void onDisconnect(BLEServer* server) override {
    deviceConnected = false;
    server->getAdvertising()->start();
  }
};

// ---- Command handling ----
static void handleCommand(const String& raw) {
  String s = raw; s.trim(); if (!s.length()) return;

#if FEAT_BATTERY
  if (s.equalsIgnoreCase("READ_BAT")) {
    float v = readVBat();
    Serial.print(F("CMD READ_BAT -> ")); Serial.println(v, 3);
    bleSendLine(String("BAT,") + String(v, 3));
    return;
  }
#endif

#if FEAT_LED
  if (s.startsWith("RGB ")) {
    int r=0,g=0,b=0;
    if (sscanf(s.c_str(),"RGB %d %d %d",&r,&g,&b)==3) {
      r = constrain(r,0,255); g = constrain(g,0,255); b = constrain(b,0,255);
      gRainbow = false;
      led_set((uint8_t)r,(uint8_t)g,(uint8_t)b);
      Serial.printf("CMD RGB -> %d,%d,%d\n", r,g,b);
      bleSendLine(String("ECHO,RGB ") + r + " " + g + " " + b);
    }
    return;
  }
  if (s.startsWith("BRIGHT ")) {
    int v=0;
    if (sscanf(s.c_str(),"BRIGHT %d",&v)==1) {
      v = constrain(v,0,255);
      led_brightness((uint8_t)v);
      Serial.printf("CMD BRIGHT -> %d\n", v);
      bleSendLine(String("ECHO,BRIGHT ") + v);
    }
    return;
  }
  if (s.equalsIgnoreCase("RAINBOW ON"))  { gRainbow = true;  Serial.println(F("CMD RAINBOW ON"));  bleSendLine("ECHO,RAINBOW ON");  return; }
  if (s.equalsIgnoreCase("RAINBOW OFF")) { gRainbow = false; Serial.println(F("CMD RAINBOW OFF")); bleSendLine("ECHO,RAINBOW OFF"); return; }
#endif

#if FEAT_IMU
  if (s.equalsIgnoreCase("START_IMU")) { gIMUEnabled = true;  Serial.println(F("CMD START_IMU")); bleSendLine("ECHO,START_IMU"); return; }
  if (s.equalsIgnoreCase("STOP_IMU"))  { gIMUEnabled = false; Serial.println(F("CMD STOP_IMU"));  bleSendLine("ECHO,STOP_IMU");  return; }
#endif

#if FEAT_PPG
  if (s.equalsIgnoreCase("START_PPG")) { gPPGEnabled = true;  Serial.println(F("CMD START_PPG")); bleSendLine("ECHO,START_PPG"); return; }
  if (s.equalsIgnoreCase("STOP_PPG"))  { gPPGEnabled = false; Serial.println(F("CMD STOP_PPG"));  bleSendLine("ECHO,STOP_PPG");  return; }
  if (s.equalsIgnoreCase("START_ALL")) { gIMUEnabled = true; gPPGEnabled = true; Serial.println(F("CMD START_ALL")); bleSendLine("ECHO,START_ALL"); return; }
  if (s.equalsIgnoreCase("STOP_ALL"))  { gIMUEnabled = false; gPPGEnabled = false; Serial.println(F("CMD STOP_ALL")); bleSendLine("ECHO,STOP_ALL");  return; }
#endif

  // echo for debug
  bleSendLine(String("ECHO,") + s);
}

// RX write callback (Arduino String–safe)
class RxCharCallbacks : public BLECharacteristicCallbacks {
  void onWrite(BLECharacteristic* c) override {
    String val = c->getValue();   // returns Arduino String
    for (size_t i=0;i<val.length();++i) {
      char ch = val[i];
      if (ch=='\r') continue;
      if (ch=='\n') { handleCommand(gCmdBuf); gCmdBuf=""; }
      else if (gCmdBuf.length()<256) gCmdBuf += ch;
    }
  }
};

// ================== setup ==================
void setup() {
  Serial.begin(115200);
  delay(200);
  Serial.println(F("\nTinZr legacy BLE (IMU+PPG normalized, solid BAT)"));

  Wire.begin();

#if FEAT_LED
  strip.begin();
  strip.setBrightness(gBrightness);
  led_apply(10,0,0); // boot color
#endif

#if FEAT_IMU
  if (lsm6.begin_I2C()) {
    lsm6.setAccelRange(LSM6DS_ACCEL_RANGE_2_G);
    lsm6.setGyroRange(LSM6DS_GYRO_RANGE_250_DPS);
    lsm6.setAccelDataRate(LSM6DS_RATE_104_HZ);
    lsm6.setGyroDataRate(LSM6DS_RATE_104_HZ);
    Serial.println(F("IMU ready."));
  } else Serial.println(F("IMU not found."));
#endif

#if FEAT_PPG
  if (particleSensor.begin(Wire, I2C_SPEED_FAST)) {
    particleSensor.setup();            // default config
    particleSensor.setPulseAmplitudeIR(0x0A);    // small LED currents to start
    particleSensor.setPulseAmplitudeRed(0x0A);
    particleSensor.setPulseAmplitudeGreen(0x08); // enable GREEN, too
    Serial.println(F("MAX30105 ready."));
  } else Serial.println(F("MAX30105 not found."));
#endif

  // ---- BLE init (legacy w/ RX) ----
  BLEDevice::init("TinZr");                  // name goes into ADV
  pServer = BLEDevice::createServer();
  pServer->setCallbacks(new MyServerCallbacks());

  BLEService* pService = pServer->createService(SERVICE_UUID);

  // TX notify characteristic
  pNotifyChar = pService->createCharacteristic(
    CHAR_TX_UUID, BLECharacteristic::PROPERTY_NOTIFY
  );
  pNotifyChar->addDescriptor(new BLE2902());

  // RX write characteristic (for commands)
  pRxChar = pService->createCharacteristic(
    CHAR_RX_UUID, BLECharacteristic::PROPERTY_WRITE | BLECharacteristic::PROPERTY_WRITE_NR
  );
  pRxChar->setCallbacks(new RxCharCallbacks());

  pService->start();

  BLEAdvertising* adv = pServer->getAdvertising();
  adv->addServiceUUID(SERVICE_UUID);
  adv->start();

#if FEAT_BATTERY
  // initial battery announce
  float v0 = readVBat();
  Serial.print(F("BOOT BAT -> ")); Serial.println(v0, 3);
  bleSendLine(String("BAT,") + String(v0, 3));
#endif

  Serial.println(F("Setup done. Advertising as TinZr…"));
}

// ================== helpers to TX ==================
static void sendIMU(){
#if FEAT_IMU
  char buf[96];
  snprintf(buf, sizeof(buf), "IMU,%.3f,%.3f,%.3f,%.2f,%.2f,%.2f,%.2f",
           ax, ay, az, gx, gy, gz, tC);
  bleSendLine(String(buf));
#if FEAT_SDLOG
  sd_append("IMU", String(buf));
#endif
#endif
}

static void sendPPG(){
#if FEAT_PPG
  char buf[64];
  snprintf(buf, sizeof(buf), "PPG,%lu,%lu,%lu",
           (unsigned long)ir, (unsigned long)red, (unsigned long)green);
  bleSendLine(String(buf));
#if FEAT_SDLOG
  sd_append("PPG", String(buf));
#endif
#endif
}

// ================== loop ==================
void loop() {
  const uint32_t now = millis();

#if FEAT_LED
  if (gRainbow && now - gLastLedMs >= 20) {
    gLastLedMs = now;
    strip.setPixelColor(0, Wheel(gHue++));
    strip.show();
  }
#endif

  // Re-announce battery right after a new connection (give CCCD time)
  static uint32_t connectAnnounceAt = 0;
  if (gJustConnected) {
    gJustConnected = false;
    connectAnnounceAt = now + 750;   // ~0.75s later: client likely subscribed
    Serial.println(F("BLE connected, scheduling BAT announce..."));
  }
  if (connectAnnounceAt && (int32_t)(now - connectAnnounceAt) >= 0) {
    connectAnnounceAt = 0;
#if FEAT_BATTERY
    float vc = readVBat();
    Serial.print(F("POST-CONNECT BAT -> ")); Serial.println(vc, 3);
    bleSendLine(String("BAT,") + String(vc, 3));
#endif
  }

#if FEAT_BATTERY
  if (now - gLastBatMs >= BAT_INTERVAL_MS) {
    gLastBatMs = now;
    float vp = readVBat();
    Serial.print(F("PERIODIC BAT -> ")); Serial.println(vp, 3);
    bleSendLine(String("BAT,") + String(vp, 3));
  }
#endif

#if FEAT_IMU
  if (gIMUEnabled && (now - gLastImuMs >= IMU_INTERVAL_MS)) {
    gLastImuMs = now;
    sensors_event_t a, g, t;
    lsm6.getEvent(&a, &g, &t);
    ax = a.acceleration.x;   // m/s^2
    ay = a.acceleration.y;
    az = a.acceleration.z;
    gx = g.gyro.x * 180.0f / PI;  // convert rad/s -> deg/s if needed
    gy = g.gyro.y * 180.0f / PI;
    gz = g.gyro.z * 180.0f / PI;
    tC = t.temperature;      // °C
  }
#endif

#if FEAT_PPG
  if (gPPGEnabled && (now - gLastPpgMs >= PPG_INTERVAL_MS)) {
    gLastPpgMs = now;
    uint32_t irv   = particleSensor.getIR();
    uint32_t redv  = particleSensor.getRed();
    uint32_t grnv  = particleSensor.getGreen();
    if (irv < NO_FINGER_THRESHOLD) { ir=red=green=0; }
    else { ir = irv; red = redv; green = grnv; }
  }
#endif

  // ===== Send streams at the fastest enabled cadence =====
  const uint32_t minPeriod = min(
    (uint32_t)(FEAT_IMU && gIMUEnabled ? IMU_INTERVAL_MS : 1000000),
    (uint32_t)(FEAT_PPG && gPPGEnabled ? PPG_INTERVAL_MS : 1000000)
  );

  static uint32_t lastSend = 0;
  if (deviceConnected && (now - lastSend >= minPeriod)) {
    lastSend = now;
    if (FEAT_IMU && gIMUEnabled) sendIMU();
    if (FEAT_PPG && gPPGEnabled) sendPPG();
  }
}

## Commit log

2025-10-23 created zip! Ready for release.
    [app3M_fat9M_16MB.csv, app3M_fat9M_fact512k_16MB.csv, app3M_spiffs9M_fact512k_16MB.csv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]
2025-10-23 new hash
    [app3M_fat9M_16MB.csv, app3M_fat9M_fact512k_16MB.csv, app3M_spiffs9M_fact512k_16MB.csv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]
2025-10-23 Added main menu for the tools in Arduino
2025-10-23 updated the boards info and created new zip
2025-10-27 Made some modifications to the GUI to modify the RGB LED on the board and show IMU and PPG data. Next I will add saving functionalities.
